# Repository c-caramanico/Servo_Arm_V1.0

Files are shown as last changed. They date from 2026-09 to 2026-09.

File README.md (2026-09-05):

## Overview
This project is a 3-axis servo-driven robotic arm with a gripper end effector, built for simple pick-and-place tasks. An ESP32 microcontroller drives the servos through a PCA9685 PWM driver and hosts a web interface, letting the arm be controlled wirelessly from any device on the same WiFi network. Servo positions persist across power cycles, so the arm resumes its last pose on reboot, and all structural components are 3D printed from the CAD/STL files included in this repository.

## Bill of Materials
| Component | Amount  | 
| --- | --- |
| Servos w/ horns | 4 |  
| Filament (w/ supports included) | 150g | 
| Esp32 | 1 | 
| Wiring | 12 | 
| PCA9685 | 1 | 
| 5V Source | 1 |

## Getting Started / Setup
1. **Print and assemble the arm.** Print the parts in [`Stl Files/`](Stl%20Files) and assemble the arm, wiring each servo to the PCA9685 as follows:

   | Channel | Joint |
   | --- | --- |
   | 0 | Base |
   | 1 | Shoulder |
   | 2 | Elbow |
   | 3 | Gripper |

**Note:** I'd recommend printing supports in PETG and the main body components in PLA; supports use roughly 50g of filament, and the body roughly 100g.

2. **Wire the electronics.** Connect the PCA9685 to the ESP32 over I2C and power the servos per [`Images/Arm_Circuit_Diagram.png`](Images/Arm_Circuit_Diagram.png).
3. **Install the Arduino IDE dependencies:**
   - ESP32 board support (via Boards Manager)
   - `Adafruit PWM Servo Driver Library` (pulls in `Adafruit_I2CDevice`)
4. **Set your WiFi credentials.** Open [`main.ino`](main.ino) and replace the `ssid` and `password` placeholders with your network's credentials.
5. **Flash the ESP32.** Select the correct board/port in the Arduino IDE and upload the sketch.
6. **Find the arm's IP address.** Open the Serial Monitor at 115200 baud — once connected, the ESP32 prints the local IP to browse to.
7. **Control the arm.** Navigate to that IP address from any device on the same WiFi network to open the web interface and move each joint.

Demo video (https://www.youtube.com/watch?v=KVW7hQpscas)

## Design
### Electrical
The arm is driven by an ESP32, which talks to a PCA9685 16-channel PWM driver over I2C rather than driving the servos directly — this offloads PWM generation from the microcontroller and lets all four servos be controlled from two I2C lines. The PCA9685 runs at 60Hz, with each servo's pulse width mapped from a 0–180° angle to a 125–625 tick range (roughly 0.5–2.5ms pulses), the standard range for hobby servos. Full wiring, including servo power distribution, is shown in the figure below:

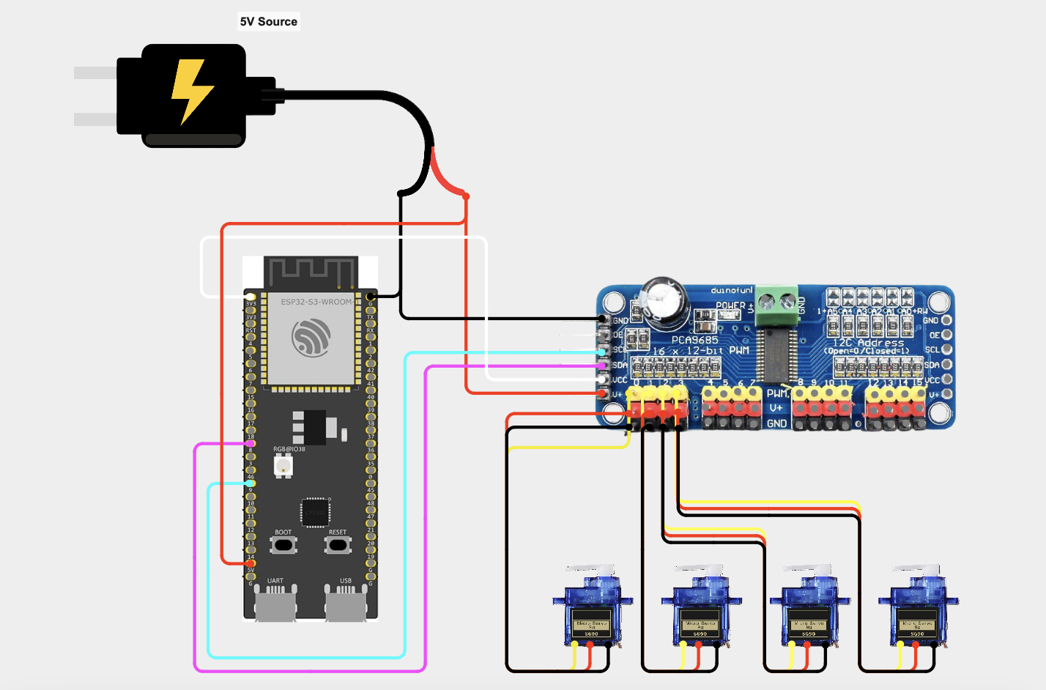
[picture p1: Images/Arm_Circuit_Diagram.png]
Arm circuit diagram


**Note:** if your microcontroller doesn't have a built-in voltage regulator, you'll need an external regulator to step the supply down to a safe 5V before it reaches the ESP32.

### Software
The ESP32 runs a single Arduino sketch, [`main.ino`](main.ino), that does three things:
- **Connects to WiFi** using the credentials set at the top of the file, then hosts a `WebServer` on port 80.
- **Serves a self-contained control UI** — the HTML/CSS/JS page is embedded directly in the sketch (`PROGMEM`) with no external dependencies, so it loads entirely from the ESP32. It renders one slider per joint (Base, Shoulder, Elbow, Gripper) and talks to the backend over two endpoints:
  - `GET /set?servo=<0-3>&angle=<0-180>` — moves the given servo and persists the new angle.
  - `GET /status` — returns the current angle of all four servos as JSON, used to sync the sliders to the arm's actual position on page load.
- **Persists servo state** using the ESP32's `Preferences` (flash-backed NVS) library, so each joint's last commanded angle is saved and restored automatically after a reset or power loss, rather than resetting to a default pose.

### CAD
Source CAD models were designed in Fusion 360 and are provided as native `.f3d`/`.f3z` files in [`Raw Cad Files/`](Raw%20Cad%20Files) for anyone who wants to edit the design. Print-ready exports of each part are provided as `.stl` files in [`Stl Files/`](Stl%20Files), covering the base, shoulder, elbow, gearbox/gear train, and gripper.

## Future / Insight

This project was my first real step into robotics and my first serious use of a 3D printer, and it came with a steep learning curve. The most challenging part was printing components to fit — dialing in tolerances and getting supports clean enough to remove without affecting fit took a lot of trial and error, especially on parts with hollow cavities and longer spans, which were more prone to warping and sagging mid-print. One improvement I'd like to try going forward is building a small buffer between a hole and its outer wall on press-fit parts, so the fit stays snug without leaving the printed plastic under constant stress. On the design side, the biggest takeaway is that this style of arm needs a wider, more stable base to handle the torque from the upper joints, along with lighter arm segments and optimized infill to cut down on the weight those joints have to carry.

Looking ahead, I'd like to scale this up into a larger arm with more degrees of freedom, and eventually bring in computer vision and machine learning — for example, using hand-tracking to record human movement and map it directly onto the arm's joints.

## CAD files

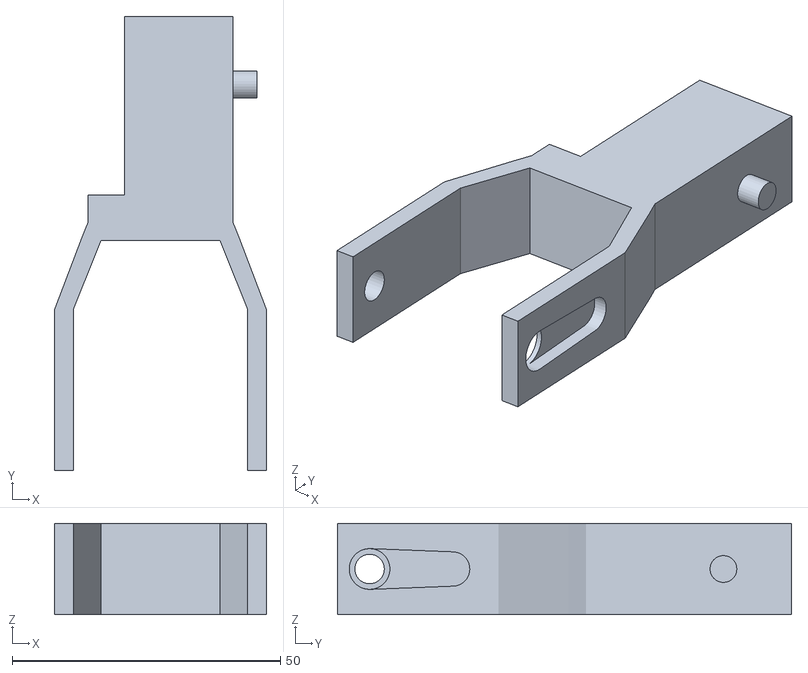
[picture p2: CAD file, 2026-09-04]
Stl Files/Shoulder.stl
39.5 x 84.6 x 17.0

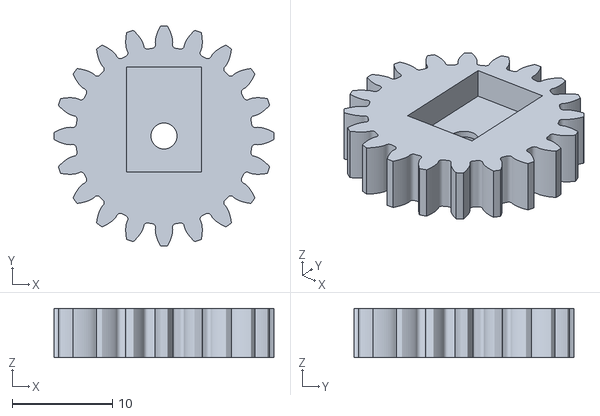
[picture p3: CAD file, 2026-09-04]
Stl Files/Gear.stl
22.0 x 22.0 x 4.90

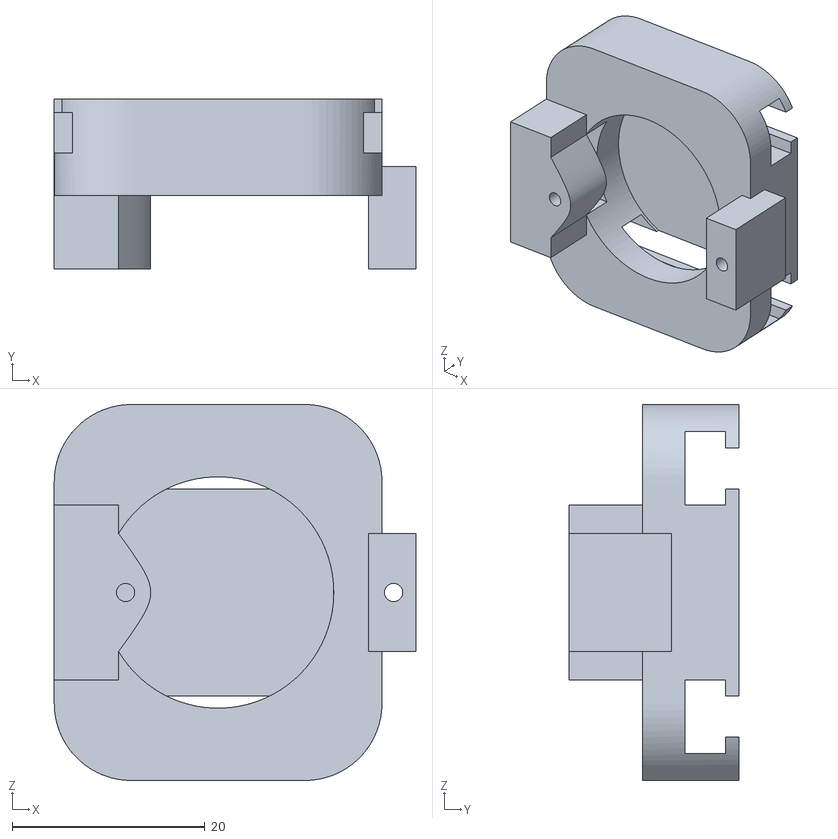
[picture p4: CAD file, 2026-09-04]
Stl Files/Gear_Box.stl
37.5 x 17.6 x 39.0

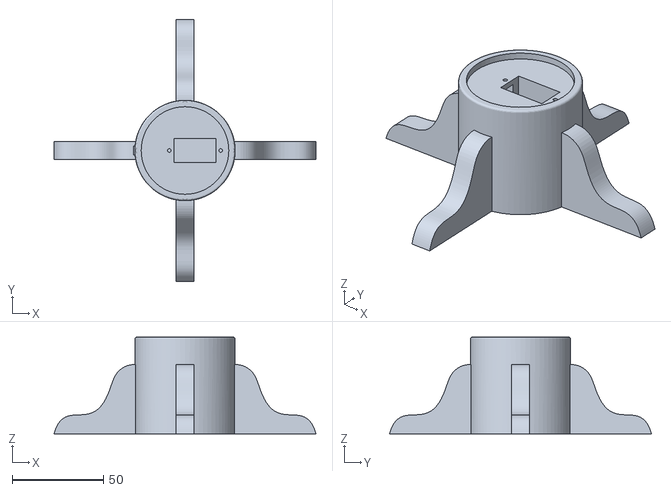
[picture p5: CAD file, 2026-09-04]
Stl Files/Base.stl
143.6 x 143.6 x 53.0

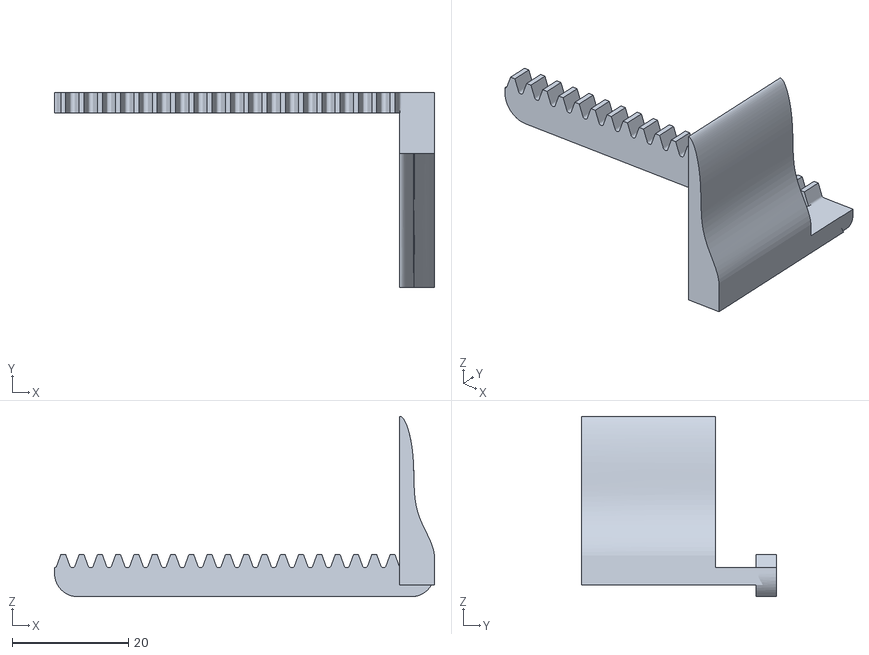
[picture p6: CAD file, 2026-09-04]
Stl Files/Gripper.stl
65.3 x 33.5 x 31.0

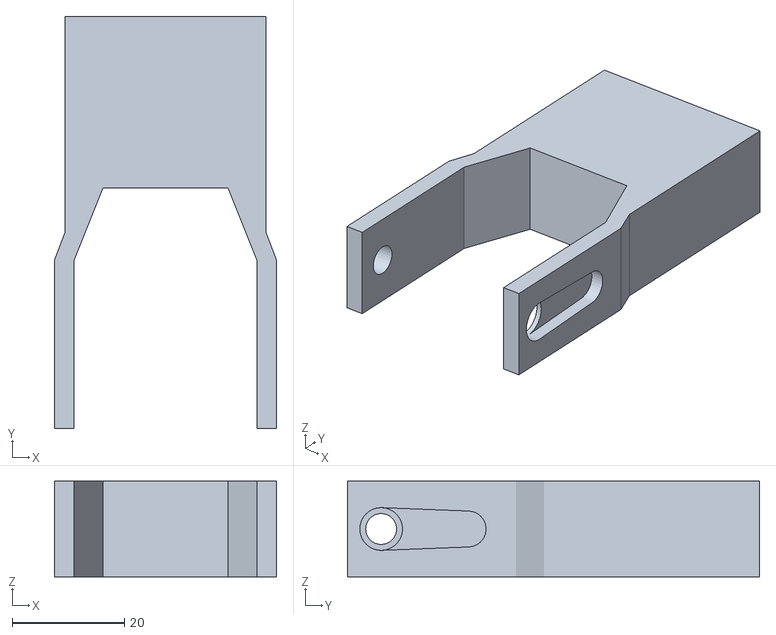
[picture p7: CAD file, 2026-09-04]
Stl Files/Elbow.stl
39.5 x 73.3 x 17.0

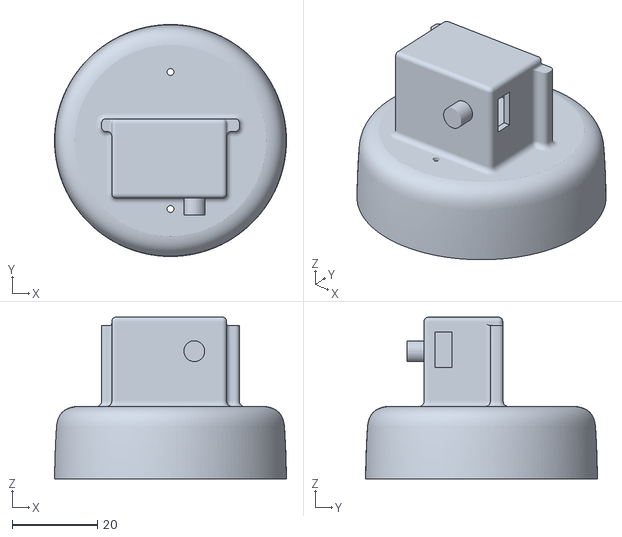
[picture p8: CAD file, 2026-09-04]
Stl Files/Revolving_Base.stl
54.5 x 54.5 x 38.0

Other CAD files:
Raw Cad Files/Base.f3d
Raw Cad Files/Elbow.f3d
Raw Cad Files/Gear_Box.f3d
Raw Cad Files/Gripper.f3d
Raw Cad Files/Revolving_Base_V2.f3d
Raw Cad Files/Servo_Gear.f3z
Raw Cad Files/Wrist.f3d

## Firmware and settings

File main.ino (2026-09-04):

#include <WiFi.h>
#include <WebServer.h>
#include <Adafruit_PWMServoDriver.h>
#include <Adafruit_I2CDevice.h>
#include <Preferences.h>
// --- WiFi Credentials ---

// Put wrt what ever your WiFi SSID and password are in the quotes below. This is the network that the ESP32 will connect to, 
//and you will use this same network to connect to the ESP32 from your computer or phone.
const char* ssid = "YourWiFiSSID"; 
const char* password = "YouRWifiPassword";

// --- Server & Hardware Setup ---
WebServer server(80);
Adafruit_PWMServoDriver board1 = Adafruit_PWMServoDriver(0x40);
Preferences prefs;

#define SERVOMIN  125 // Min pulse (0 degrees)
#define SERVOMAX  625 // Max pulse (180 degrees)
#define NUM_SERVOS 4

const int DEFAULT_SAFE_ANGLE = 90; // Fallback for brand-new flash

int currentAngle[NUM_SERVOS]; // In-memory mirror of each servo's current angle

// --- HTML & JavaScript (The Webpage) ---
const char index_html[] PROGMEM = R"rawliteral(
<!DOCTYPE html>
<html>
<head>
<meta charset="UTF-8">
<meta name="viewport" content="width=device-width, initial-scale=1">
<title>Servo Control</title>
<style>
:root{
  --bg:#0d0e12;
  --surface:#16181d;
  --border:#262930;
  --text:#f4f4f5;
  --text-dim:#8b8d94;
  --accent:#00E599;
  --accent-dim:rgba(0,229,153,0.15);
}
*{box-sizing:border-box;}
body{margin:0;padding:32px 20px 60px;background:var(--bg);color:var(--text);font-family:-apple-system,BlinkMacSystemFont,"Segoe UI",Roboto,sans-serif;}
.wrap{max-width:520px;margin:0 auto;}
.top{display:flex;align-items:center;justify-content:space-between;margin-bottom:28px;}
h1{font-size:17px;font-weight:600;letter-spacing:-.01em;margin:0;}
.status{display:flex;align-items:center;gap:6px;font-size:12px;color:var(--text-dim);}
.dot{width:7px;height:7px;border-radius:50%;background:var(--accent);box-shadow:0 0 8px var(--accent);animation:pulse 2s ease-in-out infinite;}
@keyframes pulse{0%,100%{opacity:1;}50%{opacity:.4;}}
.grid{display:grid;grid-template-columns:1fr;gap:12px;}
@media(min-width:480px){.grid{grid-template-columns:1fr 1fr;}}
.card{background:var(--surface);border:1px solid var(--border);border-radius:14px;padding:18px 18px 20px;transition:border-color .15s ease;}
.card:focus-within{border-color:var(--accent);}
.card-head{display:flex;align-items:baseline;justify-content:space-between;margin-bottom:16px;}
.joint{font-size:14px;font-weight:600;color:var(--text);}
.pin{display:block;font-size:11px;font-weight:400;color:var(--text-dim);margin-top:2px;}
.badge{font-family:'JetBrains Mono','SF Mono',Consolas,'Roboto Mono',monospace;font-size:13px;font-variant-numeric:tabular-nums;color:var(--accent);background:var(--accent-dim);border:1px solid rgba(0,229,153,0.25);padding:3px 8px;border-radius:6px;}
input[type=range]{-webkit-appearance:none;appearance:none;width:100%;height:5px;border-radius:3px;background:var(--border);outline:none;cursor:pointer;}
input[type=range]::-webkit-slider-runnable-track{-webkit-appearance:none;height:5px;border-radius:3px;background:transparent;}
input[type=range]::-webkit-slider-thumb{-webkit-appearance:none;appearance:none;width:16px;height:16px;border-radius:50%;background:var(--accent);border:2px solid var(--bg);margin-top:-5.5px;box-shadow:0 0 0 0 rgba(0,229,153,0);transition:box-shadow .15s ease,transform .15s ease;}
input[type=range]:active::-webkit-slider-thumb,input[type=range]:focus::-webkit-slider-thumb{transform:scale(1.2);box-shadow:0 0 0 6px var(--accent-dim),0 0 14px rgba(0,229,153,.6);}
input[type=range]::-moz-range-track{height:5px;border-radius:3px;background:var(--border);}
input[type=range]::-moz-range-progress{height:5px;border-radius:3px;background:var(--accent);}
input[type=range]::-moz-range-thumb{width:16px;height:16px;border-radius:50%;background:var(--accent);border:2px solid var(--bg);transition:box-shadow .15s ease,transform .15s ease;}
input[type=range]:active::-moz-range-thumb{transform:scale(1.2);box-shadow:0 0 14px rgba(0,229,153,.6);}
</style>
</head>
<body>
<div class="wrap">
  <div class="top">
    <h1>Servo Control</h1>
    <div class="status"><span class="dot"></span>ONLINE</div>
  </div>
  <div class="grid">
    <div class="card">
      <div class="card-head">
        <span class="joint">Base<span class="pin">PIN 0</span></span>
        <span class="badge" id="val0">090deg;</span>
      </div>
      <input id="slider0" type="range" min="0" max="180" value="90" oninput="updateServo(0,this.value)">
    </div>
    <div class="card">
      <div class="card-head">
        <span class="joint">Shouder<span class="pin">PIN 1</span></span>
        <span class="badge" id="val1">090deg;</span>
      </div>
      <input id="slider1" type="range" min="0" max="180" value="90" oninput="updateServo(1,this.value)">
    </div>
    <div class="card">
      <div class="card-head">
        <span class="joint">Elbow<span class="pin">PIN 2</span></span>
        <span class="badge" id="val2">090deg;</span>
      </div>
      <input id="slider2" type="range" min="0" max="180" value="90" oninput="updateServo(2,this.value)">
    </div>
    <div class="card">
      <div class="card-head">
        <span class="joint">Gripper<span class="pin">PIN 3</span></span>
        <span class="badge" id="val3">090deg;</span>
      </div>
      <input id="slider3" type="range" min="0" max="180" value="90" oninput="updateServo(3,this.value)">
    </div>
  </div>
</div>
<script>
function fillSlider(s){
  var p=(s.value-s.min)/(s.max-s.min)*100;
  s.style.background='linear-gradient(to right,var(--accent) '+p+'%,var(--border) '+p+'%)';
}
function pad(n){n=parseInt(n,10);return (n<10?'00':n<100?'0':'')+n;}
function updateServo(num,angle){
  document.getElementById('val'+num).innerText=pad(angle)+'\u00B0';
  fillSlider(document.getElementById('slider'+num));
  fetch('/set?servo='+num+'&angle='+angle);
}
document.querySelectorAll('input[type=range]').forEach(fillSlider);
window.addEventListener('DOMContentLoaded',function(){
  fetch('/status').then(function(r){return r.json();}).then(function(angles){
    angles.forEach(function(angle,num){
      var s=document.getElementById('slider'+num);
      var l=document.getElementById('val'+num);
      if(s){s.value=angle;fillSlider(s);}
      if(l){l.innerText=pad(angle)+'\u00B0';}
    });
  }).catch(function(e){console.error('status fetch failed',e);});
});
</script>
</body>
</html>
)rawliteral";

// Build the Preferences key for a given servo channel
String servoKey(int servoNum) {
  return "servo" + String(servoNum);
}

void setup() {
  Serial.begin(115200);

  // Initialize the PCA9685
  board1.begin();
  board1.setPWMFreq(60);

  // Restore last-known positions (or fall back to a safe centered angle
  // on a brand-new flash where no position has been saved yet)
  prefs.begin("arm_state", false);
  const char* jointNames[NUM_SERVOS] = {"Shoulder", "Elbow", "Wrist", "Base"};
  for (int i = 0; i < NUM_SERVOS; i++) {
    int lastAngle = prefs.getInt(servoKey(i).c_str(), DEFAULT_SAFE_ANGLE);
    board1.setPWM(i, 0, angleToPulse(lastAngle));
    currentAngle[i] = lastAngle;
    Serial.printf("Servo %d (%s) restored to %d deg\n", i, jointNames[i], lastAngle);
  }

  // Connect to WiFi
  Serial.print("Connecting to WiFi");
  WiFi.begin(ssid, password);
  while (WiFi.status() != WL_CONNECTED) {
    delay(500);
    Serial.print(".");
  }
  
  // WiFi connected
  Serial.println("\nWiFi Connected!");
  Serial.print("Go to this IP address in your browser: ");
  Serial.println(WiFi.localIP());

  // Web Server Routing
  server.on("/", []() {
    server.send(200, "text/html", index_html);
  });

  server.on("/set", []() {
    if (server.hasArg("servo") && server.hasArg("angle")) {
      int servo = server.arg("servo").toInt();
      int angle = server.arg("angle").toInt();

      if (servo < 0 || servo >= NUM_SERVOS || angle < 0 || angle > 180) {
        server.send(400, "text/plain", "Invalid servo or angle");
        return;
      }

      board1.setPWM(servo, 0, angleToPulse(angle));
      currentAngle[servo] = angle;

      // Persist so the arm resumes here after a reset/power cycle
      prefs.putInt(servoKey(servo).c_str(), angle);

      server.send(200, "text/plain", "OK");
    }
  });

  server.on("/status", []() {
    String json = "[";
    for (int i = 0; i < NUM_SERVOS; i++) {
      if (i > 0) json += ",";
      json += String(currentAngle[i]);
    }
    json += "]";
    server.send(200, "application/json", json);
  });

  server.begin();
}

void loop() {
  // Listen for incoming web requests
  server.handleClient(); 
}

// Convert angle (0-180) to PCA9685 pulse width
int angleToPulse(int ang) {
  int pulse = map(ang, 0, 180, SERVOMIN, SERVOMAX);
  return pulse;
}

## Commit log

2026-09-02 Initial Commit, Adding Models Parts
    [Base.f3d, Elbow.f3d, Gear_Box.f3d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]
2026-09-04 Add STL files, Arduino sketch, and circuit diagram
    Adds the printable STL parts, the main.ino control sketch, and the
    wiring diagram; links the diagram and demo video from the README.
    [Base.stl, Elbow.stl, Gear.stl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]
2026-09-04 Added VIdeo to ReadME
    [Base.f3d, Elbow.f3d, Gear_Box.f3d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]
